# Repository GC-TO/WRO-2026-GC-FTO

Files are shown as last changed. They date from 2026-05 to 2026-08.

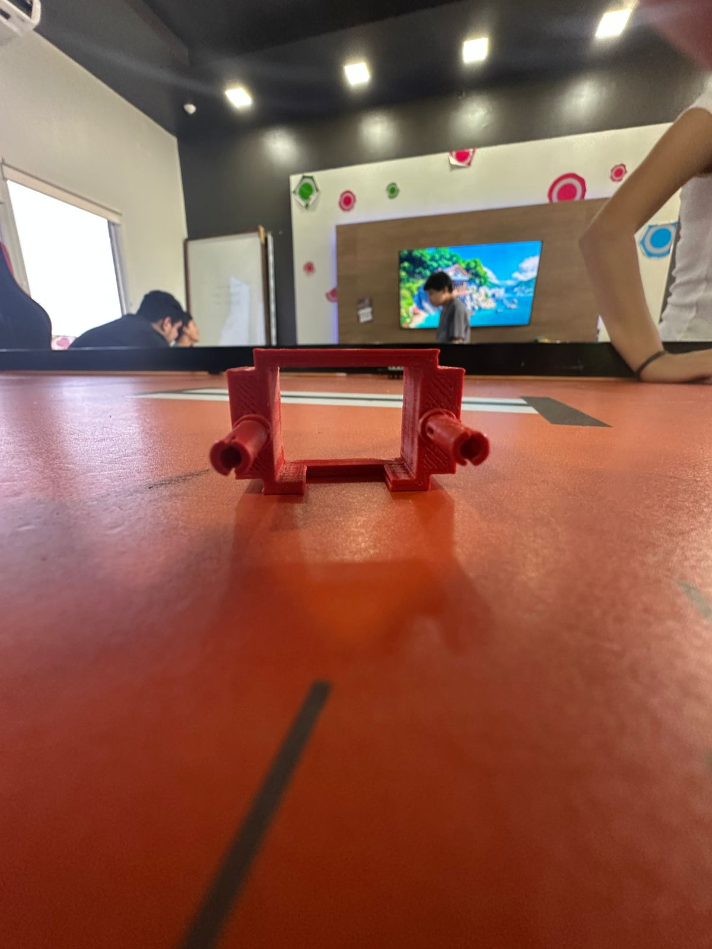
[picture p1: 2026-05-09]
Mechanics/3D Models/Sensor Case/Proto 1/Proto 1- (1).jpeg

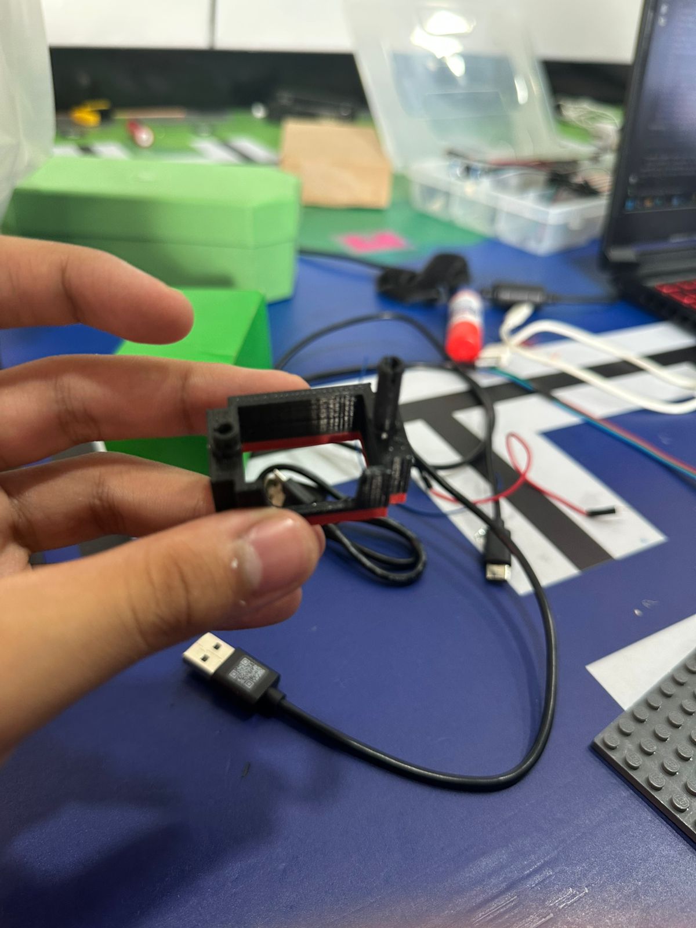
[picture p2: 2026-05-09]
Mechanics/3D Models/Sensor Case/Proto 2/Proto 2- (1).jpeg

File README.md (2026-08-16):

# WRO 2026 Future Engineers

<div align="center">









</div>

---

## 📋 Table of Contents

- [About the Team](#-about-the-team)
- [About CarloBot](#-about-carlobot)
- [Hardware Architecture](#-hardware-architecture)
- [Power Management](#-power-management)
- [Software Architecture](#-software-architecture)
- [Repository Structure](#-repository-structure)
- [Challenge Strategies](#-challenge-strategies)
- [Testing & Improvements](#-testing--improvements)
- [How to Run](#️-how-to-run)

---

## 👥 About the Team

**Team Name:** MAD Engineering
**Academy:** Game Changer Robotics Academy — El Salvador
**Competition:** WRO 2026 — Future Engineers Category
**Coach:** Carlos España

| Member | Role |
|---|---|
| **Manuel Vásquez** | Lead Programmer — central logic, PID controllers, Open & Obstacle Challenge |
| **Antonio Borst-Fortín** | Mechanical Design & Construction — chassis, steering, structural stability |
| **Daniel Salazar** | Electronics, Camera Configuration, Data Transmission & Documentation |

**MAD Engineering** is the name formed by combining the first letter of each member's name: Manuel, Antonio, and Daniel. **CarloBot** is named after our coach Carlos España, who has guided and supported us throughout the entire development process at the Game Changer Robotics Academy.

We are part of the Future Engineers division of Game Changer Robotics, a robotics academy based in El Salvador focused on developing engineering skills through real competition projects. This is our second international season — we previously competed at WRO Singapore 2025, where we represented El Salvador and brought back critical lessons that shaped the 2026 version of CarloBot.
<div align="center">
  WhatsApp Image 2026-06-20 at 15 24 34
</div>

---

## 🤖 About CarloBot

**CarloBot** is a fully autonomous self-driving robot built for the WRO 2026 Future Engineers challenge. It combines a LEGO Inventor Hub as the main locomotion controller with an ESP32 microcontroller and an OpenMV H7 Plus camera, creating a distributed sensing and processing architecture capable of navigating complex tracks, avoiding obstacles, and detecting colored traffic signs in real time — with no human input during the run.

The robot was completely redesigned this season following our participation at WRO Singapore 2025, where we identified key limitations in the previous version. The most significant structural change was reducing the chassis height from 23 cm to 16.5 cm, which lowered the center of gravity and produced a direct, measurable improvement in stability: the robot went from a maximum of 55% speed in corners without losing traction, to running consistently at 75% — a 36% increase in operational speed without compromising control.

Every design decision in CarloBot responds to a specific engineering constraint identified through testing. The move to three independent LiDAR buses came from an I²C address conflict. The switch to a non-blocking state machine in the ESP32 came from PUPRemote connection losses. The choice of LAB over RGB for color detection came from failures under competition venue lighting. Nothing in this build was theoretical — everything was driven by a test, a failure, and a fix.

### Key Design Principles

| Principle | Implementation | Measurable Result |
|---|---|---|
| **Compactness** | Height reduced 28.3% (23 cm → 16.5 cm), motors redistributed toward center | Corner speed increased from 55% to 75% |
| **Rigidity** | Full LEGO brick chassis, no flex in sensor mounting points | Consistent sensor readings at competition speed |
| **Controllability** | Dual PID system — turn PID (IMU) + trajectory PID (heading lock) | Zero wall contacts in Open Challenge testing |
| **Reliability** | Non-blocking ESP32 architecture, timeout fallbacks on all channels | Zero PUPRemote disconnections since implementation |

---

## 🔧 Hardware Architecture

CarloBot is built around three processing units that communicate in real time:

```
┌─────────────────┐        UART (115200 bps)      ┌───────────────────────────┐
│  OpenMV H7 Plus │ ─────────────────────────────► │          ESP32            │
│  (Pro_CAM.py)   │   C:<color>,P:<position>\n     │      (Con_ESP32.py)       │
│                 │   every 80ms / on change        │                           │
│  480 MHz STM32  │                                 │  ┌─────────────────────┐  │
│  32 MB SDRAM    │                                 │  │ TF-Luna ×3 (LiDAR)  │  │
│  QVGA 320×240   │         SoftI2C @ 400 kHz      │  │ SoftI2C #1 GPIO21/22│  │
└─────────────────┘   ◄─────────────────────────── │  │ SoftI2C #2 GPIO26/27│  │
                          3 independent I²C buses   │  │ SoftI2C #3 GPIO15/13│  │
                                                    │  └─────────────────────┘  │
                                                    └─────────────┬─────────────┘
                                                                  │ PUPRemote
                                                         Port F   │ LPF2 protocol
                                                                  ▼
                                                    ┌─────────────────────────┐
                                                    │     LEGO Inventor Hub   │
                                                    │     (Ope/Obs_Chall.py)  │
                                                    │                         │
                                                    │  Motor E → Traction     │
                                                    │  Motor B → Steering     │
                                                    │  IMU 6-axis (heading)   │
                                                    │  7.3V Li-ion battery    │
                                                    └─────────────────────────┘
```

### Components

| Component | Specs | Role |
|---|---|---|
| **LEGO Inventor Hub** | 7.3V Li-ion · 6 ports · 6-axis IMU | Main locomotion controller — motors, turning, wall-following logic |
| **ESP32 WROOM-32** | 240 MHz dual-core · 520 KB SRAM · 3.0–3.6V | Sensor bridge — reads all 3 LiDARs, relays camera data to Hub via PUPRemote |
| **OpenMV H7 Plus** | STM32H7 480 MHz · 32 MB SDRAM · <150 mA | Computer vision — detects colored blocks, determines position, drives LED brightness PID |
| **TF-Luna LiDAR ×3** | 850 nm VCSEL · 0.2–8 m · ±6 cm · 100 Hz default | Distance sensing — corner detection, wall-following, obstacle position confirmation |
| **Motor E (Port E)** | LEGO Large Angular Motor | Traction — rear axle, counterclockwise direction |
| **Motor B (Port B)** | LEGO Large Angular Motor | Steering — front axle, clockwise direction, ±60 range in competition |

### ESP32 Pin Mapping

| Sensor | SDA | SCL | Bus |
|---|---|---|---|
| TF-Luna 1 (Front) | GPIO 22 | GPIO 21 | SoftI2C #1 |
| TF-Luna 2 (Right) | GPIO 27 | GPIO 26 | SoftI2C #2 |
| TF-Luna 3 (Left) | GPIO 13 | GPIO 15 | SoftI2C #3 |
| UART from OpenMV | RX: GPIO 4 | — | UART1 @ 115,200 bps |
| PUPRemote to Hub | Port F cable | — | LPF2 protocol |

> **Why 3 independent I²C buses?** All three TF-Luna sensors share the same I²C hardware address (0x10). Multiplexing or address remapping adds latency and complexity. Three independent SoftI2C buses eliminate address conflicts and allow all three sensors to be read in a non-blocking rotation without interfering with each other.

---

## ⚡ Power Management

| Component | Voltage | Typical Current | Power |
|---|---|---|---|
| LEGO Hub (processing) | 7.3V | ~300 mA | ~2.2 W |
| Drive motor (under load) | 7.3V | 400–800 mA | 2.9–5.8 W |
| Steering motor | 7.3V | 100–300 mA | 0.7–2.2 W |
| ESP32 (240 MHz, active) | 3.3V | ~50 mA | ~0.17 W |
| 3× LiDAR TF-Luna | 5V | ~210 mA avg | ~1.05 W |
| OpenMV H7 Plus | 3.3–5V | <150 mA | ~0.75 W |
| **Total (estimated)** | — | — | **~8–12 W active** |

The LEGO Hub battery (7.3V / ~2,100 mAh / ~15.3 Wh) provides approximately **1.28 hours** of autonomy at full load. Each competition run (~3 minutes) consumes roughly **0.5 Wh — about 3.3% of total capacity**, guaranteeing stable voltage and consistent motor behavior throughout the entire event. A reserve battery strategy is used: the robot always starts competition at full charge.

---

## 💻 Software Architecture

The codebase is split across four Python files, each targeting a specific piece of hardware:

### `Pro_CAM.py` — OpenMV Camera Vision Module

Runs on the **OpenMV H7 Plus**. Captures frames at **QVGA (320×240)** resolution and:

- Detects **red** and **green** blobs using LAB color thresholds:
  - Red: `(0, 58, 14, 127, -128, 127)`
  - Green: `(30, 90, -128, -10, 0, 127)`
- **Why LAB over RGB?** LAB's L (lightness) channel is fully decoupled from chrominance. Color thresholds remain stable even when ambient light changes — critical in venues with different lighting than our training environment.
- Determines obstacle **position** (left = 1, right = 2) using two ROIs on the lower half of the frame:
  - `ROI_LEFT = (20, 170, 140, 16)` / `ROI_RIGHT = (160, 170, 140, 16)`
- Manages **adaptive PWM lighting** (hard-capped at 60%) via a brightness PID loop:
  - `PWM_new = (1 − α) · PWM_curr + α · (PWM_curr + Kp · brightness_error)`
  - α = 0.20 · Kp = 0.6 · Target brightness = 60 · Max PWM = 60%
- Transmits results over **UART** as `C:<color>,P:<position>\n` at up to 80ms intervals; forces a heartbeat send every 250ms regardless of change
- On startup, sends 10 safe-state messages `C:0,P:0` before entering the main loop

**Camera data codes sent to ESP32:**

| Detected Situation | cam Channel Code |
|---|---|
| Nothing detected | 0 |
| Red — left side | 11 |
| Red — right side | 12 |
| Green — left side | 21 |
| Green — right side | 22 |

### `Con_ESP32.py` — ESP32 Sensor Bridge

Runs on the **ESP32** in MicroPython. Acts as a real-time sensor aggregator and communication bridge:

- Reads distance from **3× TF-Luna LiDAR sensors** over three independent SoftI2C buses at 400 kHz
- Each reading uses command `0x5A 0x05 0x00 0x06 0x65`; 9-byte response validated with checksum `CS = (Σ byte[0..7]) & 0xFF == byte[8]`; distance extracted as `d = byte[2] | (byte[3] << 8)`
- Uses a **non-blocking state machine** per sensor (FREE → WAITING → FREE):
  - State FREE: if 6ms elapsed → send command → transition to WAITING
  - State WAITING: if 3ms elapsed → read → validate → advance to next sensor → FREE
  - Effective update rate: **~37 Hz per sensor** · Full 3-sensor cycle: **~27 ms**
- UART parsing uses direct byte arithmetic — `color = byte - 0x30` — with no `decode()` or `split()` to minimize heap pressure
- Exposes data to the LEGO Hub via **PUPRemote** (LPF2 protocol) on Port F:
  - `cam` channel: `int16` — camera detection code
  - `dist` channel: `3× int16` — LiDAR distances in mm (0–32,767)
- Calls `pr.process()` every ~1ms; if connection is lost, automatically calls `conectar_hub()` to re-negotiate and `restaurar_canales()` to republish last known values — zero manual restart required
- `bytearray` buffer for UART reads avoids allocating new heap objects per chunk
- `gc.collect()` runs every 2 seconds to prevent heap fragmentation
- Timeout fallbacks: LiDAR silent >300ms → distance resets to 0; camera silent >250ms → cam resets to 0

### `Ope_Chall.py` — Open Challenge Controller

Runs on the **LEGO Inventor Hub** via PyBricks. Controls the robot for the **Open Round**:

- Auto-detects track direction at startup from lateral LiDAR readings — no manual setup needed
- If right sensor > 1,000 mm first → **clockwise** (`sigue_pared1`); if left → **counter-clockwise** (`sigue_pared2`)
- Wall-following uses `drive_with_heading_lock()` with ±12° heading corrections relative to accumulated base heading `p`
- Corner detection: > 1,000 mm → 500ms confirmation → PID turn → 3 consecutive wall readings < 1,000 mm → resume
- After **12 corners** (3 full laps), drives forward to finish line and stops

### `Obs_Chall.py` — Obstacle Challenge Controller

Runs on the **LEGO Inventor Hub** via PyBricks. Extends the Open Challenge with full bidirectional obstacle evasion:

- Auto-detects track direction at startup (`sentido = 1` CCW / `sentido = 2` CW) — runs the appropriate exit maneuver (`salida_counter()` or `salida_clock()`) then enters a loop of 11 navigation + corner cycles
- Variable `daniel` accumulates ±90° per completed corner as an absolute heading offset, preventing IMU drift across multiple laps
- Variable `probot` tracks post-evasion state (0 = normal, 1/2 = last block color, 3 = fallback search)

**Clockwise evasion:**
- 🔴 **Red block** → `rojo()`: +55° turn right → front wall follow → return to heading
- 🟢 **Green block** → `verde()`: −40° turn left → left wall follow → return to heading

**Counter-clockwise evasion (mirrored):**
- 🔴 **Red block** → `rojo_ccw()`: +40° turn → left wall follow → return
- 🟢 **Green block** → `verde_ccw()`: −55° turn → front wall follow → return

**Utility functions:**
- `look_for_block()`: creeps forward at low speed until the camera detects a block or the front LiDAR reads below the threshold — prevents acting on stale camera data
- `move_for_distance()`: converts target distance in cm to a timed drive call using wheel circumference (17.5 cm)

### Shared PID Controllers

**`giro_con_imu(steering, target_angle, speed)`** — Full PID rotation to exact IMU heading.

| Parameter | Value | Reasoning |
|---|---|---|
| Kp | 2.0 | Main correction force |
| Ki | 0.0 | Disabled — prevents error accumulation in short turns |
| Kd | 0.8 | Dampens oscillation near target |
| Tolerance | ±2° | Stop condition |
| Deadband | ±1° | Prevents micro-oscillation |
| Min speed | 200 (Obs_Chall) / 100 (Ope_Chall) | Higher floor reduces slow final approach time |

**`drive_with_heading_lock(heading, speed, sensor, value)`** — Forward driving with IMU heading correction.

| Parameter | Value | Reasoning |
|---|---|---|
| Kp | 2.2 | Faster response while moving |
| Ki | 0.1 | Corrects slow drift without instability |
| Kd | 1.5 | Strong damping for straight-line stability |
| MAX_STEER | ±50 | Clamps steering correction |
| Deadband | 0.2° | Prevents unnecessary corrections at speed |
| Confirmation | 5 readings | Prevents false-positive stops |

---

## 📁 Repository Structure

```
📦 WRO-2026-GC-FTO/
├── 📄 README.md
├── 📁 Code/
│   └── 📁 Cam Code/
│       ├── 🐍 Pro_CAM.py        # OpenMV H7 Plus — color detection & UART transmission
│       ├── 🐍 Con_ESP32.py      # ESP32 — LiDAR reading & PUPRemote bridge
│       ├── 🐍 Ope_Chall.py      # LEGO Hub — Open Challenge (wall following, 3 laps)
│       └── 🐍 Obs_Chall.py      # LEGO Hub — Obstacle Challenge (traffic sign avoidance)
├── 📁 Electronics/
│   └── 📁 Diagram Cam/          # Wiring diagrams — ESP32, LiDAR, and OpenMV connections
├── 📁 General Photos/
│   └── 📁 DREAM TEAM/
│       └── 📁 At Work/          # Team photos during development and testing sessions
└── 📁 Mechanics/
    └── 📁 3D Models/
        └── 📁 Sensor Case/      # 3D printed cases for LiDAR and camera sensor mounting
```

---

## 🏁 Challenge Strategies

### Open Challenge

1. CarloBot starts and reads both lateral LiDAR sensors simultaneously
2. If the **right** sensor exceeds 1,000 mm first → **clockwise** lap (`sigue_pared1`)
3. If the **left** sensor exceeds 1,000 mm first → **counter-clockwise** lap (`sigue_pared2`)
4. At each corner: detect open space (> 1,000 mm) → 500ms confirmation → 90° IMU-guided turn → wall reacquisition (3 consecutive readings < 1,000 mm) → resume
5. After **12 corners** (3 full laps), robot drives to finish line and stops

**Competition speed:** `drive_speed = 700` — balanced between speed and reliability.

### Obstacle Challenge

Same as Open Challenge, plus:

- 🔴 **Red** → pass right — `rojo()`: +55° turn → wall follow → return
- 🟢 **Green** → pass left — `verde()`: −40° turn → wall follow → return
- Camera re-read after each evasion confirms clearance before resuming

**Competition speed:** `drive_speed = 500` (CW) / `drive_speed = 400` (CCW) — reduced to give camera pipeline sufficient processing time.

### Risk Management

| Risk | Root Cause | Mitigation |
|---|---|---|
| LiDAR dropout | Loose cable or I²C timeout | `DIST_TIMEOUT_MS = 300` → distance resets to 0 |
| Stale camera reading | UART loss or OpenMV lag | `CAM_TIMEOUT_MS = 250` → cam resets to 0 |
| IMU heading drift | Accumulated angle error | `imu.reset_heading(0)` at every program start |
| False corner trigger | Track irregularity or object | 5 consecutive readings confirmation required |
| PUPRemote disconnect | Blocking code in ESP32 | `pr.process()` called every ~1ms, non-blocking architecture |
| Battery performance drop | Discharge during session | Reserve battery strategy; checked via `battery.voltage()` at startup |

---

## 🧪 Testing & Improvements

### Test Log

| # | Objective | Failure Observed | Change Applied | Status |
|---|---|---|---|---|
| 1 | Reduce robot height | High-speed corner instability | Motor redistribution → 16.5 cm | ✅ Fixed |
| 2 | LiDAR corner threshold | False corners at 800 mm | Raised threshold to 1,000 mm | ✅ Fixed |
| 3 | Non-blocking ESP32 | PUPRemote lost connection due to `sleep_ms()` | State machine FREE/WAITING per sensor | ✅ Fixed |
| 4 | Red LAB threshold | False negatives under competition lighting | Broadened LAB range to `(0, 58, 14, 127, -128, 127)` | ✅ Fixed |
| 5 | Post-corner trajectory | Robot loses wall reference after evasion at corner | Under development | ⚠️ Pending |

### Key Engineering Lessons

**Software architecture matters as much as hardware.** The `sleep_ms()` blocking PUPRemote was not apparent until we measured the actual Hub update frequency. Once we understood the root cause, the fix was straightforward — but finding it required systematic measurement.

**LAB over RGB is an engineering decision, not a preference.** RGB thresholds shift with ambient light intensity. LAB's L channel separates luminance from chrominance — color detection stays stable even when total brightness changes. This eliminated an entire category of failures.

**Lower center of mass equals more stability — and the data proves it.** Height reduction from 23 cm to 16.5 cm allowed a speed increase from 55% to 75% in corners. The improvement was immediate and directly tied to the physical change.

**Test one variable at a time.** Changing multiple parameters simultaneously makes it impossible to identify which change caused the improvement — or the failure.

---

## ▶️ How to Run

### Requirements

- LEGO SPIKE / Inventor Hub with [Pybricks](https://pybricks.com/) firmware
- ESP32 flashed with [MicroPython](https://micropython.org/) (v1.20+)
- OpenMV H7 Plus with [OpenMV IDE](https://openmv.io/pages/download)
- `pupremote` library installed on both the LEGO Hub and ESP32

### Steps

1. **Flash `Pro_CAM.py`** onto the OpenMV H7 Plus via OpenMV IDE. Starts automatically on power-up.
2. **Flash `Con_ESP32.py`** onto the ESP32 via Thonny. Copy as `boot.py` for automatic startup.
3. **Connect the ESP32** to LEGO Hub Port F via PUPRemote cable (modified PoweredUp cable with SDA, SCL, 5V, GND exposed).
4. **Upload** `Ope_Chall.py` or `Obs_Chall.py` to the LEGO Hub via Pybricks.
5. Press the **center button** on the Hub to start the run.

> **Startup order matters:** Power the OpenMV camera first, then the ESP32, then press the Hub button. The camera sends 10 safe-state `C:0,P:0` messages on boot — starting in the wrong order can result in stale zero readings on the first few cam values.

---

<div align="center">

**MAD Engineering — WRO 2026 Future Engineers**
*Game Changer Robotics Academy · El Salvador*
*Built with 🧱 LEGO · 🐍 MicroPython · 📷 Computer Vision · 📡 LiDAR · ⚙️ PID Control*

</div>

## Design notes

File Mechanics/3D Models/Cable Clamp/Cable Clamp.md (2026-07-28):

# Cable Clamp

Mechanical part used to secure the wiring on CarloBot, particularly the wires running to the ESP32. This folder documents three design iterations.

## Files

- **Cable Carlobot 1.stl** — first prototype. Dimensions: 44.00 x 32.38 x 15.00 mm. This version was too large: cables slipped out easily during testing.

- **Cable Carlobot 2.stl** — second prototype. Dimensions: 44.00 x 32.38 x 8.00 mm. Height was reduced to 8 mm (matching a standard LEGO piece height), which also reduced print time. Length and width were unchanged from the first prototype.

- **Cable Carlobot 3.stl** — third prototype (current version). Dimensions: 
  30.00 x 28.00 x 8.00 mm. Length and width were reduced from the second prototype while keeping the same height. This solved the cable-slipping issue specifically for the wires going to the ESP32.

## Design rationale

Each iteration targeted a specific problem found during testing: first reducing height for faster printing, then reducing the footprint to grip the wires more tightly. All three files are kept in this folder to document the design process, not just the final part.

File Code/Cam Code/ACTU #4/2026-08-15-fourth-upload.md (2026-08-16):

# Obstacle Challenge: bidirectional navigation + camera calibration update

This update replaces Obs_Chall.py with a major expansion that handles both 
lap directions instead of only clockwise, and updates the camera's 
detection settings.

Changed files:

- Obs_Chall.py — added:
  · main() — reads left/right distance once at the start to decide the lap 
    direction, then dispatches to the correct set of routines (clockwise 
    or counter-clockwise) for all 11 sections of the run.
  · A full counter-clockwise mirror of every navigation function: 
    verde_ccw(), rojo_ccw(), rojo2_ccw(), verde2_ccw(), nada_ccw(), 
    nada2_ccw(), navegacion_ccw(), curva_r_ccw(), curva_v_ccw(), 
    curvas_ccw(). Turn angles and steering are flipped relative to their 
    clockwise counterparts.
  · salida_counter() / salida_clock() — starting-direction routines that 
    read the camera right after leaving the parking lot to decide which 
    branch to enter first.
  · move_for_distance(speed, distance, angle) — new helper that converts a 
    target distance in cm into drive time using wheel circumference.
  · Sensor mapping bug fixed inside drive_with_heading_lock(): sensor 2 
    (front) was previously a placeholder that always returned False; now 
    sensor 1 = front, 2 = left, 3 = right, all correctly implemented.
  · Fixed the "danile" typo from the previous commit.
  · Still unresolved: salida_bloque() is dead code — references "color" 
    without reading it first, and nothing in the file calls it. Needs 
    removal or a fix in a future commit.

- Pro_CAM.py — camera calibration update:
  · Sensor resolution raised from QQVGA (160x120) to QVGA (320x240).
  · ROI_LEFT and ROI_RIGHT resized and repositioned to match the new, 
    larger frame (from 70x8 px near the top of the frame to 140x16 px 
    lower in the frame).
  · RED_THRESHOLD widened significantly (L: 30-85 to 0-58, A/B: near full 
    range) to detect red pillars under a broader range of lighting 
    conditions.
  · DEBUG and DRAW_DEBUG both set to True for on-field tuning; should be 
    set back to False before the actual competition runs, since debug 
    printing and rectangle drawing cost processing time per frame.
  · Note: some in-file comments still refer to "QQVGA" near the resolution 
    and ROI settings — these are now outdated and should be updated to 
    avoid confusion, since the sensor actually runs at QVGA in this version.

Unchanged in this update: Con_ESP32.py, Ope_Chall.py — same versions as 
the previous upload.

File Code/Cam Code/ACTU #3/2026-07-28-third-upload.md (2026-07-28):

# ESP32 Hub reconnection + Obstacle Challenge state machine + Open Challenge tuning

This update adds automatic Hub reconnection to the ESP32 firmware, rewrites 
the Obstacle Challenge into a full state machine covering parking-lot exit 
and corner logic, and tunes the Open Challenge corner behavior.

Changed files:

- Con_ESP32.py — replaced with a version that adds robustness to the 
  PUPRemote connection with the LEGO Hub. The previous version only called 
  pr.process() in the loop without checking if a connection actually 
  existed. The new version:
  · Adds max_packet_size=16 to PUPRemoteSensor, matching Pybricks' 
    recommended configuration for this channel setup.
  · Waits and confirms PUPRemote has negotiated a connection with the Hub 
    on startup (conectar_hub()), instead of assuming it's connected.
  · Detects a dropped connection every loop cycle and reconnects 
    automatically (Hub restart, low battery, interference), instead of 
    silently sending data to a channel nobody is reading.
  · Re-sends the last known camera and distance values right after a 
    reconnection (restaurar_canales()), so the Hub doesn't start with 
    stale/zeroed data.
  · Resets timing references after a reconnection so timeouts don't 
    misfire due to the time spent disconnected.

- Obs_Chall.py — replaced with a full state-machine rewrite. The previous 
  version only reacted to a pillar once the camera saw it; this version 
  adds the complete lap logic: parking-lot exit, corner handling, and 
  active searching when no pillar is visible yet.
  · main() — reads left/right distance at the start to decide initial 
    turning direction (salida_counter() for counter-clockwise start, 
    salida_clock() for clockwise start).
  · salida_counter() / salida_clock() — handle exiting the parking lot 
    section for each starting direction.
  · look_for_block() — creeps the car forward while polling the camera, 
    until either a pillar is detected or a distance limit is reached.
  · navegacion() — rewritten as a state machine using a new "probot" 
    variable (0-3) that tracks how many pillars have already been handled 
    in the current section.
  · curva_r() / curva_v() — corner routines now branch based on "probot", 
    deciding whether to keep searching for another pillar after the turn.
  · Main loop now runs a full "while vueltas < 11" cycle instead of two 
    fixed calls, covering all 3 laps plus the parking-lot sections.

- Ope_Chall.py — tuning and connection changes, no new logic branches.
  · PUPRemoteHub port changed from Port.D to Port.F.
  · Startup sequence now drives forward using the front sensor as a stop 
    condition (drive_with_heading_lock) before checking left/right 
    distance, instead of starting the direction check immediately.
  · Corner turn angle reduced from 60° to 50°, confirmation count reduced 
    from 5 to 3, post-turn wait reduced from 700 ms to 600 ms, and the 
    wall-following speed reduced from 700 to 500.
  · Removed a debug-only pre-turn front-distance check.

Unchanged in this update: Pro_CAM.py (no functional differences from the 
previous commit).

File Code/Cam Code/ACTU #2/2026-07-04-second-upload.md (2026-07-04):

This update replaces the ESP32 firmware with a non-blocking version and implements the actual traffic-sign navigation logic for the Obstacle Challenge.

Changed files:

* Con\_ESP32.py — full rewrite. The previous version blocked the main loop
with sleep\_ms() between each TF-Luna command and its response, and parsed
camera data with string decode()/split(). The new version:
· Reads the 3 TF-Luna sensors with a non-blocking state machine
(TF\_ESTADO\_LIBRE / TF\_ESTADO\_ESPERANDO), so no sensor read stalls the loop.
· Validates each TF-Luna packet with its checksum before accepting the
distance value.
· Parses the camera's UART line directly on bytes (no decode()/split()),
combining color + position into a single value (0, 11, 12, 21, 22) sent
to the Hub over one PUPRemote channel ("cam").
· Applies timeouts: camera value resets to 0 if OpenMV goes silent for
250 ms, and each LiDAR resets to 0 if its sensor stops responding for
300 ms.
· Uses PUPRemoteSensor to expose "cam" and "dist" channels to the Hub,
replacing the previous debug-only print statements.
* Obs\_Chall.py — expanded from a wall-following test stub into the actual
Obstacle Challenge behavior. Added:
· verde() / rojo() — steering routines that react to a detected green or
red pillar (keep left / keep right).
· navegacion() — reads the camera channel and decides which routine to run
based on the color and position received.
· curva\_r() / curva\_v() / curvas() — corner-handling routines chained after
each straight section.

Unchanged in this update: Ope\_Chall.py and Pro\_CAM.py (no functional
differences from the previous commit).

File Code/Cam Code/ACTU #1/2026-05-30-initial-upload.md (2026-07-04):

This first update adds the four core Python programs that make CarloBot run.

- Pro_CAM.py — runs on the OpenMV H7 camera with LED shield. Detects red/green 
  traffic signs using LAB color thresholds and reports color + position 
  (left/right) over UART to the ESP32.

- Con_ESP32.py — runs on the ESP32. Reads the 3 TF-Luna LiDAR sensors 
  (front, left, right) over SoftI2C, receives the color/position data from 
  the camera over UART, and relays everything to the LEGO Inventor Hub via 
  PUPRemote (Port D).

- Ope_Chall.py — runs on the LEGO Inventor Hub. Controls the robot during 
  the Open Challenge: detects driving direction, follows the wall using 
  LiDAR distance, and completes 3 laps (12 corners) before stopping.

- Obs_Chall.py — runs on the LEGO Inventor Hub. Extends the Open Challenge 
  logic to react to the traffic signs detected by the camera, adjusting 
  the lane position (right for red, left for green).

Hardware connected in this update: 3x TF-Luna LiDAR (SoftI2C) + OpenMV H7 
camera (UART) → ESP32 → LEGO Inventor Hub (PUPRemote).

No mechanical or documentation changes in this commit — code only.

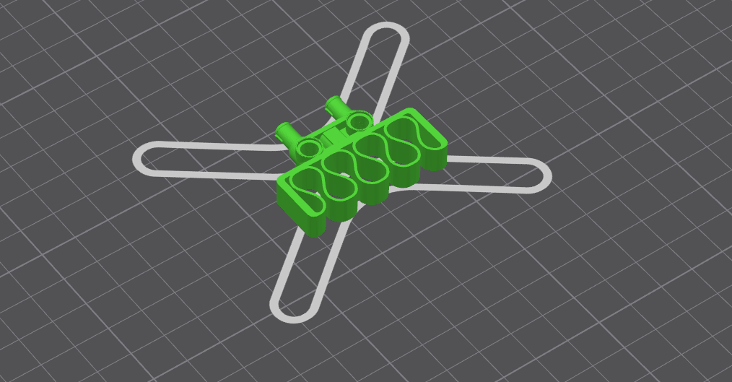
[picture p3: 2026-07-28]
Mechanics/3D Models/Cable Clamp/Proto 2/Foto 1.png

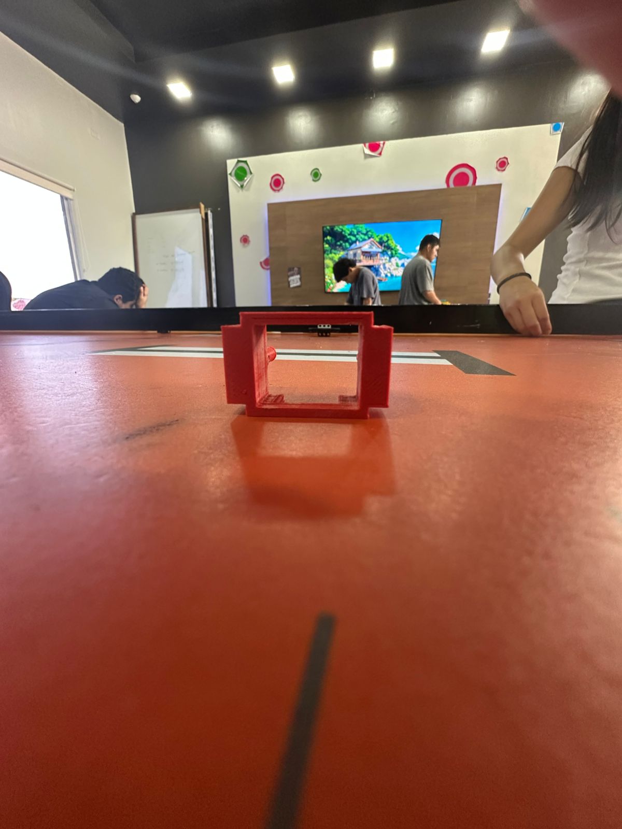
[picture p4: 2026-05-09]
Mechanics/3D Models/Sensor Case/Proto 1/Proto 1- (4).jpeg

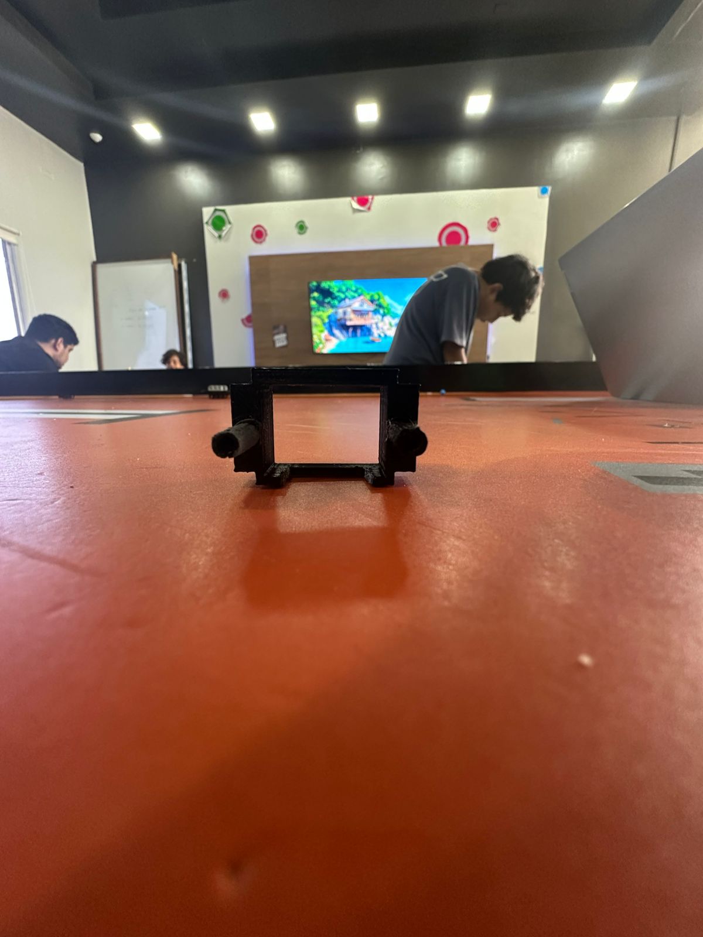
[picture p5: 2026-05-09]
Mechanics/3D Models/Sensor Case/Proto 3/Proto 3- (4).jpeg

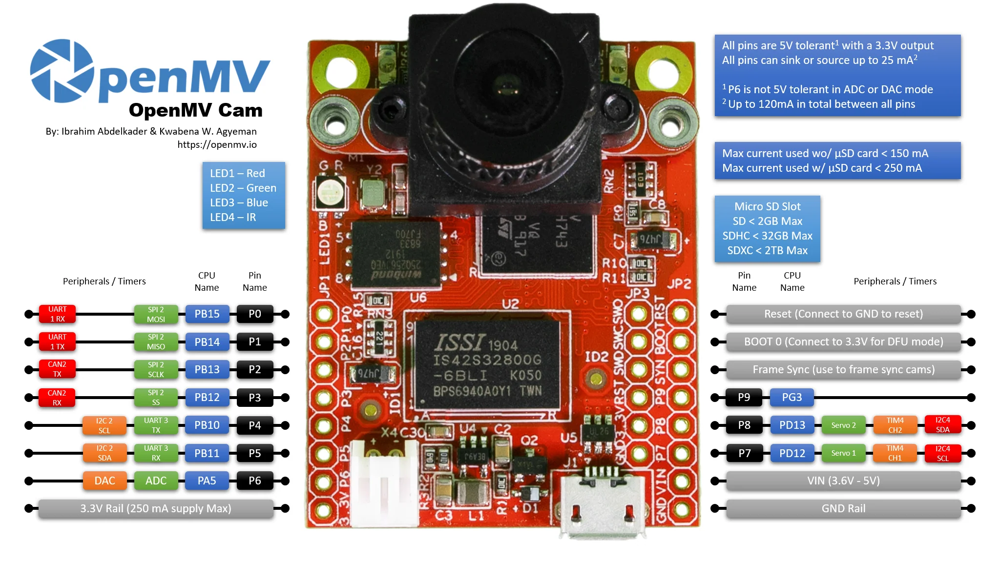
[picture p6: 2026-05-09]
Electronics/Diagram Cam/OpenMV H7 Plus.webp

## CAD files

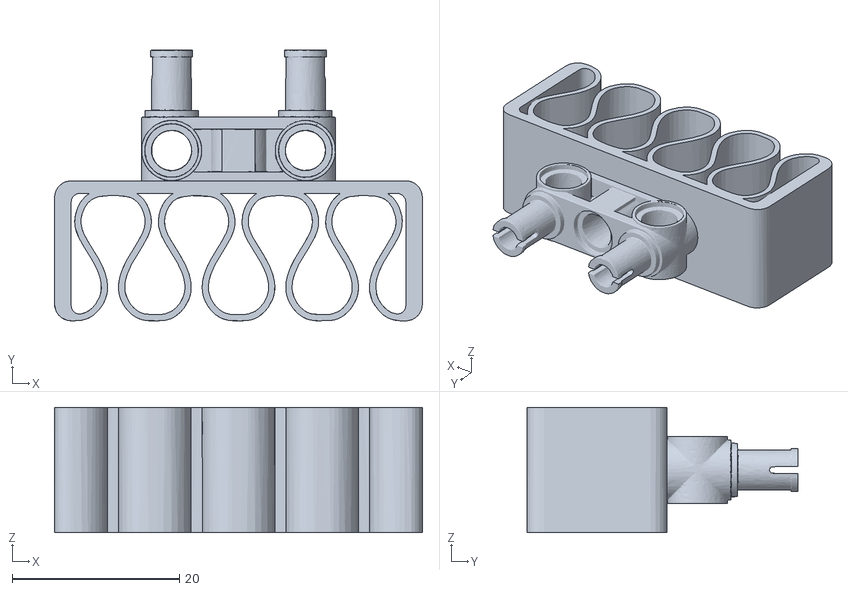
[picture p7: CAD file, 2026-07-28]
Mechanics/3D Models/Cable Clamp/Proto 1/Cable Carlobot 1.stl
44.0 x 32.4 x 15.0

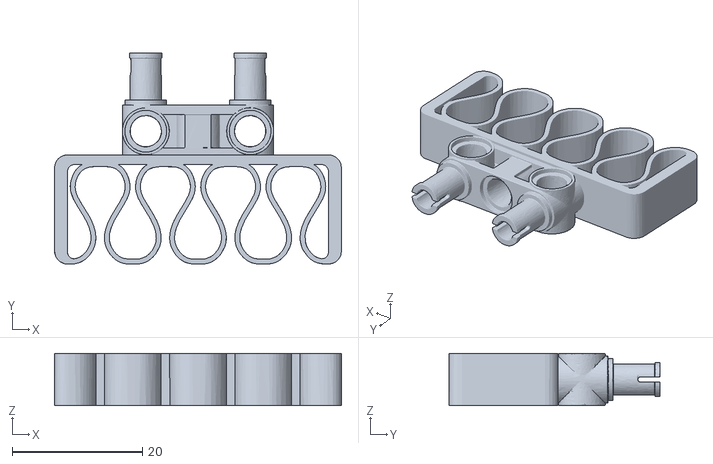
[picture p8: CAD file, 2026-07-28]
Mechanics/3D Models/Cable Clamp/Proto 2/Cable Carlobot 2.stl
44.0 x 32.4 x 8.00

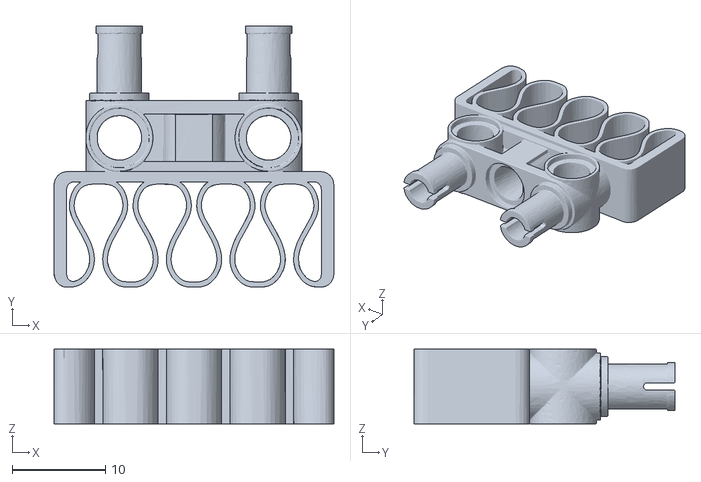
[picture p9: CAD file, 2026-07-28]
Mechanics/3D Models/Cable Clamp/Proto 3/Cable Carlobot 3.stl
30.0 x 28.0 x 8.00

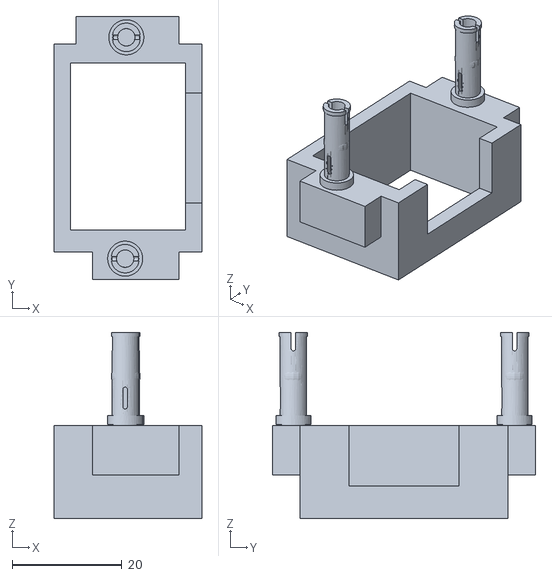
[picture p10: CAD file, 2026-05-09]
Mechanics/3D Models/Sensor Case/Proto 1/Proto 1.stl
27.0 x 48.0 x 34.0

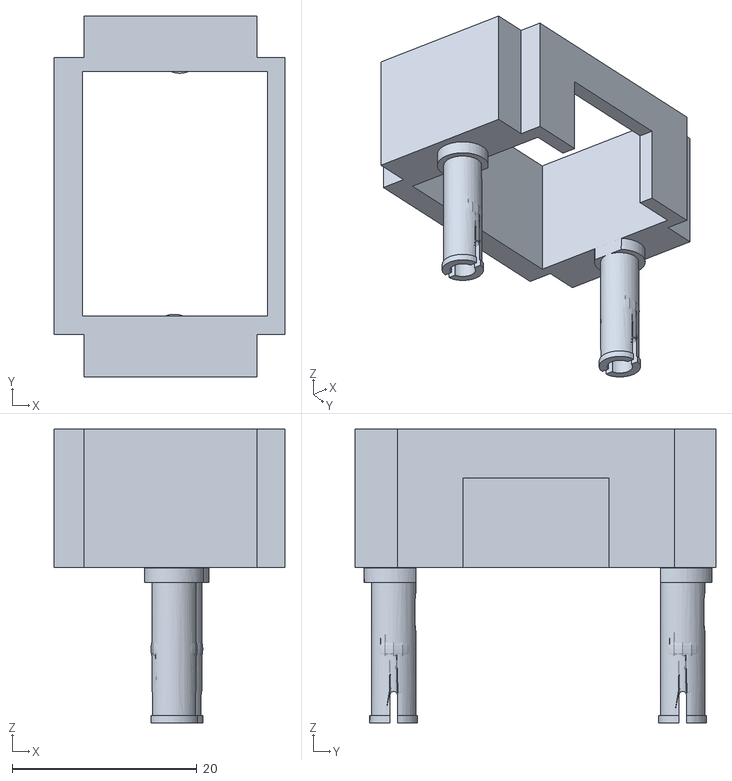
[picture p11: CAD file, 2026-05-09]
Mechanics/3D Models/Sensor Case/Proto 2/Proto 2.stl
25.0 x 39.1 x 31.8

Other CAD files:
Mechanics/3D Models/Sensor Case/Proto 4/Sensor tapa.stl

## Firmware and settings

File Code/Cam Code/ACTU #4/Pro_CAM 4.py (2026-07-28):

import sensor
import image
import time
import pyb
import gc
from pyb import Pin, Timer

# =========================================================
# CONFIGURACION GENERAL
# =========================================================
DEBUG = True          # Cambiar a True solo para pruebas con computadora
DRAW_DEBUG = True     # Cambiar a True solo si quieres ver rectangulos en OpenMV IDE

LED_RED = pyb.LED(1)
LED_GREEN = pyb.LED(2)
LED_BLUE = pyb.LED(3)

# =========================================================
# ARRANQUE AUTONOMO SEGURO
# =========================================================
LED_RED.on()
time.sleep_ms(300)
LED_RED.off()

# Espera para que ESP32 / alimentacion se estabilicen
time.sleep_ms(3000)

# =========================================================
# UART HACIA ESP32
# OpenMV P4 TX -> ESP32 GPIO4 RX
# GND comun
# =========================================================
uart = pyb.UART(3, 115200, timeout_char=20)

# Enviar estado seguro al iniciar
for i in range(10):
    uart.write("C:0,P:0\n")
    time.sleep_ms(50)

LED_GREEN.on()
time.sleep_ms(200)
LED_GREEN.off()

# =========================================================
# CONFIGURACION DE LUZ PWM VARIABLE, LIMITADA AL 60%
# =========================================================
# Para LED no hace falta 50 kHz. 500 Hz es mas estable.
light = Timer(2, freq=500).channel(1, Timer.PWM, pin=Pin("P6"))

TARGET_BRIGHTNESS = 60

MIN_PWM = 5
MAX_PWM = 60      # Limite maximo: nunca pasa de 60%

KP = 0.6
ALPHA = 0.20

pwm = 10

# Arranque suave para evitar pico de corriente
light.pulse_width_percent(0)
time.sleep_ms(500)

for p in range(0, pwm + 1):
    light.pulse_width_percent(p)
    time.sleep_ms(80)

# =========================================================
# CONFIGURACION DE CAMARA
# =========================================================
sensor.reset()
sensor.set_pixformat(sensor.RGB565)

# QQVGA = 160 x 120
sensor.set_framesize(sensor.QVGA)

# Bloquear automaticos para estabilidad de color
sensor.set_auto_gain(False)
sensor.set_auto_exposure(False)
sensor.set_auto_whitebal(False)

sensor.skip_frames(time=2000)

clock = time.clock()

LED_BLUE.on()
time.sleep_ms(200)
LED_BLUE.off()

# =========================================================
# ROIS PARA QQVGA
# =========================================================
# Imagen QQVGA: 160 x 120
# Franja de deteccion inferior
ROI_LEFT = (20, 170, 140, 16)
ROI_RIGHT = (160, 170, 140, 16)

# ROI para medir brillo general
ROI_BRIGHTNESS = (50, 40, 60, 40)

# =========================================================
# THRESHOLDS DE COLOR
# =========================================================
RED_THRESHOLD = (0, 58, 14, 127, -128, 127)
GREEN_THRESHOLD = (30, 90, -128, -10, 0, 127)

# En QQVGA las areas son menores que en QVGA
PIXELS_THRESHOLD = 50
AREA_THRESHOLD = 50
MIN_TOTAL_AREA = 70

# =========================================================
# TIEMPOS
# =========================================================
SEND_INTERVAL_MS = 80
FORCE_SEND_MS = 250
PRINT_INTERVAL_MS = 800
LED_INTERVAL_MS = 300
GC_INTERVAL_MS = 2000

last_send = time.ticks_ms()
last_force_send = time.ticks_ms()
last_print = time.ticks_ms()
last_led = time.ticks_ms()
last_gc = time.ticks_ms()

last_color = -1
last_position = -1

# =========================================================
# FUNCIONES
# =========================================================
def clamp(value, min_value, max_value):
    if value < min_value:
        return min_value
    if value > max_value:
        return max_value
    return value


def update_light(img):
    global pwm

    try:
        stats = img.get_statistics(roi=ROI_BRIGHTNESS)
        brightness = stats.l_mean()

        error = TARGET_BRIGHTNESS - brightness

        desired_pwm = pwm + (KP * error)
        desired_pwm = clamp(desired_pwm, MIN_PWM, MAX_PWM)

        pwm = (1 - ALPHA) * pwm + ALPHA * desired_pwm
        pwm = clamp(pwm, MIN_PWM, MAX_PWM)

        light.pulse_width_percent(int(pwm))

        return brightness

    except Exception:
        # Si falla la lectura de brillo, dejar luz en valor seguro
        pwm = MIN_PWM
        light.pulse_width_percent(int(pwm))
        return -1


def get_area(img, roi, threshold, draw_color=None):
    total_area = 0

    try:
        blobs = img.find_blobs(
            [threshold],
            roi=roi,
            pixels_threshold=PIXELS_THRESHOLD,
            area_threshold=AREA_THRESHOLD,
            merge=True
        )

        for blob in blobs:
            area = blob.w() * blob.h()
            total_area += area

            if DRAW_DEBUG and draw_color is not None:
                img.draw_rectangle(blob.rect(), color=draw_color)

    except Exception:
        total_area = 0

    return total_area


def detect_color_position(img):
    if DRAW_DEBUG:
        img.draw_rectangle(ROI_LEFT, color=(0, 255, 255))
        img.draw_rectangle(ROI_RIGHT, color=(255, 0, 255))

    # Areas por color y lado
    left_red = get_area(img, ROI_LEFT, RED_THRESHOLD, (255, 0, 0))
    right_red = get_area(img, ROI_RIGHT, RED_THRESHOLD, (255, 0, 0))

    left_green = get_area(img, ROI_LEFT, GREEN_THRESHOLD, (0, 255, 0))
    right_green = get_area(img, ROI_RIGHT, GREEN_THRESHOLD, (0, 255, 0))

    total_red = left_red + right_red
    total_green = left_green + right_green

    # Filtro contra ruido
    if total_red < MIN_TOTAL_AREA and total_green < MIN_TOTAL_AREA:
        return 0, 0, total_red, total_green

    # Color dominante y posicion del mismo color
    if total_red >= total_green:
        color = 1  # rojo

        if left_red >= right_red:
            position = 1
        else:
            position = 2

    else:
        color = 2  # verde

        if left_green >= right_green:
            position = 1
        else:
            position = 2

    return color, position, total_red, total_green


def send_uart(color, position, force=False):
    global last_color, last_position, last_send, last_force_send

    now = time.ticks_ms()

    changed = (color != last_color) or (position != last_position)
    send_time_ok = time.ticks_diff(now, last_send) >= SEND_INTERVAL_MS
    force_time_ok = time.ticks_diff(now, last_force_send) >= FORCE_SEND_MS

    if send_time_ok and (changed or force or force_time_ok):
        uart.write("C:%d,P:%d\n" % (color, position))

        last_color = color
        last_position = position
        last_send = now

        if force or force_time_ok:
            last_force_send = now


def heartbeat():
    global last_led

    now = time.ticks_ms()

    if time.ticks_diff(now, last_led) >= LED_INTERVAL_MS:
        LED_GREEN.toggle()
        last_led = now


def clean_memory():
    global last_gc

    now = time.ticks_ms()

    if time.ticks_diff(now, last_gc) >= GC_INTERVAL_MS:
        gc.collect()
        last_gc = now


def debug_print(color, position, red_area, green_area, brightness):
    global last_print

    if not DEBUG:
        return

    now = time.ticks_ms()

    if time.ticks_diff(now, last_print) >= PRINT_INTERVAL_MS:
        if color == 1:
            color_text = "Rojo"
        elif color == 2:
            color_text = "Verde"
        else:
            color_text = "Nada"

        print(
            color_text,
            "| Pos:", position,
            "| Red:", red_area,
            "| Green:", green_area,
            "| Brillo:", brightness,
            "| PWM:", int(pwm),
            "| FPS:", clock.fps(),
            "| Mem:", gc.mem_free()
        )

        last_print = now


# =========================================================
# LOOP PRINCIPAL
# =========================================================
print("OpenMV lista en QQVGA con PWM limitado al 60%.")

while True:
    try:
        clock.tick()

        img = sensor.snapshot()

        # Actualizar intensidad LED sin pasar de 60%
        brightness = update_light(img)

        # Detectar color y posicion
        color, position, red_area, green_area = detect_color_position(img)

        # Enviar a ESP32
        send_uart(color, position)

        # Mantenimiento
        heartbeat()
        clean_memory()

        # Debug opcional
        debug_print(color, position, red_area, green_area, brightness)

    except Exception as e:
        # Estado seguro si algo falla
        uart.write("C:0,P:0\n")

        LED_RED.on()
        time.sleep_ms(80)
        LED_RED.off()

        if DEBUG:
            print("Error loop:", e)

        time.sleep_ms(50)

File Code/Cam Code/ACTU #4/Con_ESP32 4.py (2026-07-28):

from machine import UART, Pin, SoftI2C
from time import sleep_ms, ticks_ms, ticks_diff
from pupremote import PUPRemoteSensor, SPIKE_ULTRASONIC
import gc


# =========================================================
# CONFIGURACION GENERAL
# =========================================================
DEBUG = False          # True solo para pruebas con Thonny
PRINT_MS = 500         # Imprimir cada 500 ms si DEBUG = True

# PUPRemote debe atenderse con frecuencia mientras negocia con el Hub.
CONNECTION_POLL_MS = 2

# Tiempos de trabajo
DIST_SEND_MS = 20
CAM_SEND_MS = 40
TF_READ_GAP_MS = 6
TF_WAIT_MS = 3

CAM_TIMEOUT_MS = 250
DIST_TIMEOUT_MS = 300


# =========================================================
# CONFIGURACION TF-LUNA
# =========================================================
TF_ADDR = 0x10
CMD_GET_MM = b'\x5A\x05\x00\x06\x65'
I2C_FREQ = 400000

i2c_1 = SoftI2C(scl=Pin(21), sda=Pin(22), freq=I2C_FREQ)
i2c_2 = SoftI2C(scl=Pin(26), sda=Pin(27), freq=I2C_FREQ)
i2c_3 = SoftI2C(scl=Pin(15), sda=Pin(13), freq=I2C_FREQ)
i2c_buses = (i2c_1, i2c_2, i2c_3)


# =========================================================
# UART DESDE OPENMV
# OpenMV P4 TX -> ESP32 GPIO4 RX
# GND comun
# Formato: C:x,P:y\n
# =========================================================
uart = UART(1, baudrate=115200, rx=Pin(4), timeout=0)
buffer = bytearray()


# =========================================================
# PUPREMOTE HACIA HUB LEGO
# 16 bytes: configuracion recomendada para Pybricks.
# =========================================================
pr = PUPRemoteSensor(
    sensor_id=SPIKE_ULTRASONIC,
    power=True,
    max_packet_size=16,
)

# Mantener exactamente los mismos nombres, formatos y orden en el Hub.
pr.add_channel("cam", "h")
pr.add_channel("dist", "hhh")

pr.update_channel("cam", 0)
pr.update_channel("dist", 0, 0, 0)


# =========================================================
# VARIABLES
# =========================================================
valor_cam = 0
ultimo_valor_cam_enviado = -1

distancias = [0, 0, 0]
ultimo_ok_dist = [ticks_ms(), ticks_ms(), ticks_ms()]

tf_index = 0
TF_ESTADO_LIBRE = 0
TF_ESTADO_ESPERANDO = 1
tf_estado = TF_ESTADO_LIBRE
tf_cmd_ms = ticks_ms()

ultimo_tf_read = ticks_ms()
ultimo_envio_dist = ticks_ms()
ultimo_envio_cam = ticks_ms()
ultimo_print = ticks_ms()
ultimo_gc = ticks_ms()
ultimo_rx_cam = ticks_ms()


# =========================================================
# FUNCIONES
# =========================================================
def limitar_int16(valor):
    if valor < 0:
        return 0
    if valor > 32767:
        return 32767
    return valor


def marcar_timeout_si_corresponde(idx, now):
    if ticks_diff(now, ultimo_ok_dist[idx]) > DIST_TIMEOUT_MS:
        distancias[idx] = 0


def tick_tfluna(now):
    """Lee los tres TF-Luna por turnos sin bloquear el bucle principal."""
    global tf_estado, tf_cmd_ms, tf_index, ultimo_tf_read

    bus = i2c_buses[tf_index]

    if tf_estado == TF_ESTADO_LIBRE:
        if ticks_diff(now, ultimo_tf_read) < TF_READ_GAP_MS:
            return

        try:
            bus.writeto(TF_ADDR, CMD_GET_MM)
            tf_cmd_ms = now
            tf_estado = TF_ESTADO_ESPERANDO
        except Exception as error:
            marcar_timeout_si_corresponde(tf_index, now)
            tf_index = (tf_index + 1) % 3
            ultimo_tf_read = now

            if DEBUG:
                print("Error comando TF-Luna:", tf_index, error)
        return

    if ticks_diff(now, tf_cmd_ms) < TF_WAIT_MS:
        return

    try:
        data = bus.readfrom(TF_ADDR, 9)

        if len(data) == 9 and data[0] == 0x59 and data[1] == 0x59:
            checksum = (
                data[0] + data[1] + data[2] + data[3]
                + data[4] + data[5] + data[6] + data[7]
            ) & 0xFF

            if checksum == data[8]:
                distancia = data[2] | (data[3] << 8)
                distancias[tf_index] = limitar_int16(distancia)
                ultimo_ok_dist[tf_index] = now
            else:
                marcar_timeout_si_corresponde(tf_index, now)
        else:
            marcar_timeout_si_corresponde(tf_index, now)

    except Exception as error:
        marcar_timeout_si_corresponde(tf_index, now)

        if DEBUG:
            print("Error lectura TF-Luna:", tf_index, error)

    tf_index = (tf_index + 1) % 3
    ultimo_tf_read = now
    tf_estado = TF_ESTADO_LIBRE


def procesar_linea_openmv(linea):
    """Convierte b'C:1,P:2' en 0, 11, 12, 21 o 22."""
    try:
        if not linea:
            return None

        idx_coma = linea.find(b",")
        if idx_coma < 0:
            return None

        c_part = linea[:idx_coma]
        p_part = linea[idx_coma + 1:]

        if not (c_part.startswith(b"C:") and p_part.startswith(b"P:")):
            return None

        if len(c_part) != 3 or len(p_part) != 3:
            return None

        color = c_part[2] - 0x30
        posicion = p_part[2] - 0x30

        if color not in (0, 1, 2) or posicion not in (0, 1, 2):
            return None

        if color == 0 or posicion == 0:
            return 0

        return color * 10 + posicion

    except Exception:
        return None


def leer_openmv():
    global valor_cam, ultimo_rx_cam

    if uart.any() <= 0:
        return

    data = uart.read()
    if not data:
        return

    buffer.extend(data)

    if len(buffer) > 80:
        buffer[:] = buffer[-40:]

    while True:
        idx = buffer.find(b"\n")
        if idx < 0:
            break

        linea = bytes(buffer[:idx]).strip()
        buffer[0:idx + 1] = b""

        nuevo_valor = procesar_linea_openmv(linea)
        if nuevo_valor is not None:
            valor_cam = nuevo_valor
            ultimo_rx_cam = ticks_ms()


def actualizar_stale_camara(now):
    global valor_cam

    if ticks_diff(now, ultimo_rx_cam) > CAM_TIMEOUT_MS:
        valor_cam = 0


def enviar_distancias(now):
    global ultimo_envio_dist

    if ticks_diff(now, ultimo_envio_dist) >= DIST_SEND_MS:
        pr.update_channel("dist", distancias[0], distancias[1], distancias[2])
        ultimo_envio_dist = now


def enviar_camara(now):
    global ultimo_envio_cam, ultimo_valor_cam_enviado

    if (
        valor_cam != ultimo_valor_cam_enviado
        or ticks_diff(now, ultimo_envio_cam) >= CAM_SEND_MS
    ):
        pr.update_channel("cam", valor_cam)
        ultimo_valor_cam_enviado = valor_cam
        ultimo_envio_cam = now


def restaurar_canales():
    """Publica nuevamente los ultimos valores tras una conexion/reconexion."""
    pr.update_channel("cam", valor_cam)
    pr.update_channel("dist", distancias[0], distancias[1], distancias[2])
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

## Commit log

2026-05-09 Creating Filing Folders by Category
    The new structure for GitHub has been established, based on key tasks and areas of focus. This was previously discussed with the group.
    [Proto 1.stl, Proto 2.stl, Proto 3.stl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]
2026-05-30 First ACTU Programming Update #1
    The programming for the challenges and the robot's operation—including the camera and ESP 32 settings—is loaded for the first time.
2026-07-04 The second version of the code is being uploaded.
    We've uploaded the most up-to-date code with significant changes. The code for the camera and the Open Challenge remains the same, but with minor adjustments. However, the ESP32 code was optimized to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
2026-07-04 ESP32 rewrite to non-blocking architecture + Obstacle Challenge navigation logic (June update, uploaded late)
2026-07-28 Add third update: ESP32 reconnection, Obstacle Challenge rewrite, Open Challenge tuning
    Adds 2026-07-28-third-upload.md documenting this update, plus the four updated program files: Con_ESP32.py, Obs_Chall.py, Ope_Chall.py and Pro_CAM.py is unchanged. See the .md file for full details o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
2026-07-28 Add Cable Clamp folder: 3 design iterations
    Adds Mechanics/3D Models/Cable Clamp/ with three STL prototypes (Cable Carlobot 1, 2, 3) and a Cable Clamp.md documenting the iteration history: reducing height for faster printing, then reducing the footprint to stop cables (especially to the ESP32) from slipping out.
    See the Cable Clamp.md in this folder for full details on each prototype.
    [Cable Carlobot 1.stl, Cable Carlobot 2.stl, Cable Carlobot 3.stl]
2026-08-15 Revise README with team and project updates
    Updated team name and details, improved CarloBot description, and added power management and testing sections.
2026-08-16 Add fourth update: bidirectional Obstacle Challenge + camera calibration
    Adds 2026-08-15-fourth-upload.md documenting this update, plus the four program files: Obs_Chall.py (now handles both clockwise and counter-clockwise laps), Pro_CAM.py (resolution raised to QVGA, ROI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
2026-08-16 Revise wiring and sensor configurations in README
    Updated README.md to reflect changes in wiring and sensor configurations, including adjustments to I²C buses and LAB color thresholds.
2026-08-16 Insert CarloBot image in README
    Added an image of CarloBot to the README.
2026-10-30 Add fifth update: parking maneuvers + speed constants + corner-correction overhaul
    Adds 2026-10-30-fifth-upload.md documenting this update, plus Obs_Chall.py—now includes 5 parking manoeuvres (parqueo2-6), a refactor of hardcoded speeds into named constants, and correctionClock/correction Counter, replacing fixed 90-degree turn corrections and a reverse-steering fix in drive_with_heading_lock(). Con_ESP32.py, Ope_Chall.py, and Pro_CAM.py are unchanged from the previous upload. See the .md file for full details of what changed.
2026-11-07 Add full CarloBot 3D model (Studio 2.0 render)
    Adds Model CarloBot/CarloBotRender.stl — the complete 3D model of the robot, built in Studio 2.0 and passed through a render pass to reduce vertex count and file size for easier sharing and viewing.
2026-11-12 Add robot photos by category
    Photos of CarloBot sorted into folders: robot views, on the field, electronics and wiring, 3D printed parts, Steren battery label, camera calibration, testing sessions, team and workshop, and notes.
2026-11-12 Add background photos of the previous robot
    Photos of La Tigresa del Oriente, our robot from the previous season, in folders TO1 to TO6 from the first chassis to the latest version.
2026-11-12 Add CarloBot V2 3D model and renders
    STL file of the CarloBot V2 3D model in Model 3D, and seven renders of it in Photo 3D.
